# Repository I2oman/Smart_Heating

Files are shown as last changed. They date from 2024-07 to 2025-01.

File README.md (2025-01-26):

# Smart Heating Controller Attachment

This repository contains the design, firmware, and web interface for a **Smart Heating Controller Attachment** that enhances an existing heating system with Wi-Fi functionality. With this attachment, you can control your heating remotely, set timers, and enjoy advanced automation without replacing the original controller.

<p align="center">
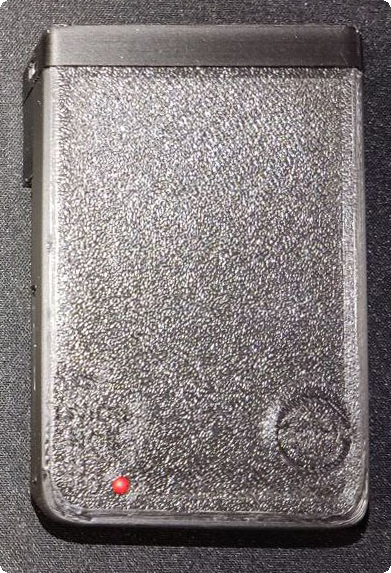
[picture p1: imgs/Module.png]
Controller Attachment
  
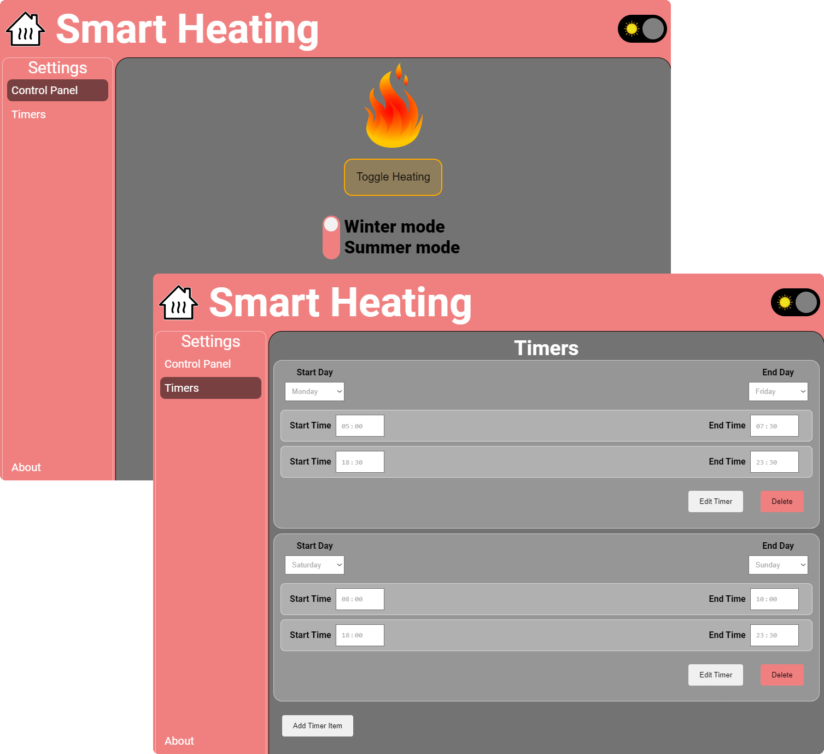
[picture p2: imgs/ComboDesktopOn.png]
Web Interface
  
</p>

---

## Features

### 1. **Wi-Fi Control**

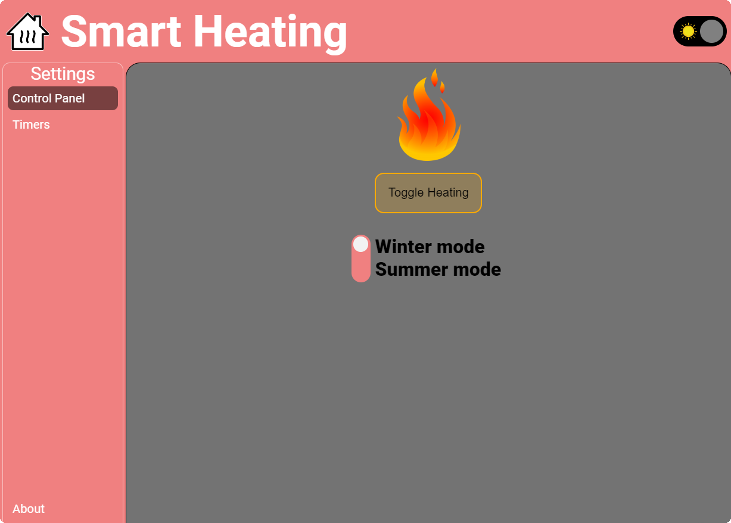
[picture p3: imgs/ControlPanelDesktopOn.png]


- Turn your heating system **ON** or **OFF** remotely via a web interface.
- Adjust settings conveniently without physical access to the controller.

#### Light and Dark Themes, On/Off State, and Mobile/Desktop View

The web interface is responsive and supports:

- **Light and Dark themes** with a toggle switch.

<p align="center">
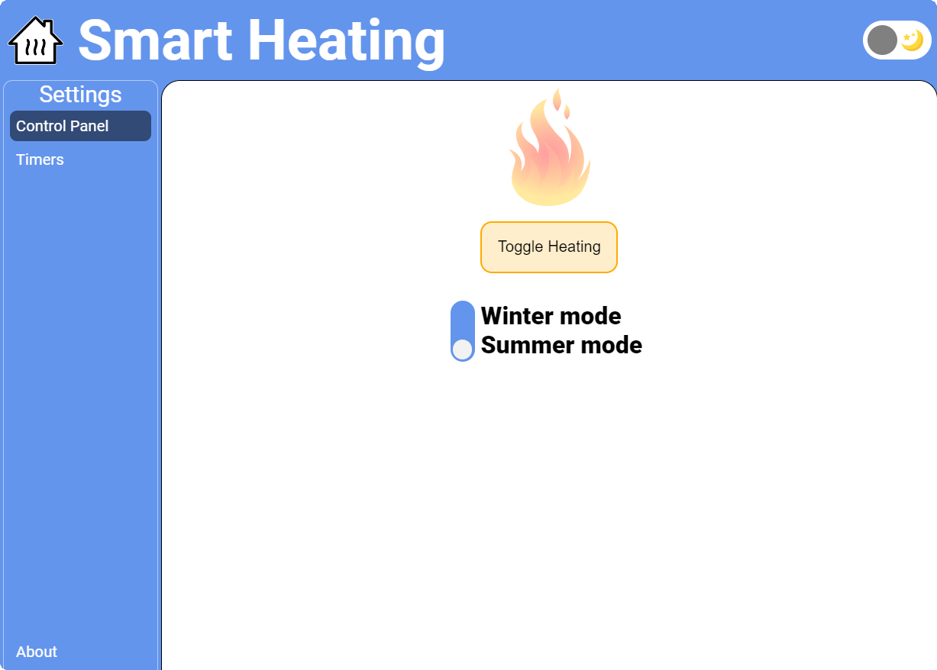
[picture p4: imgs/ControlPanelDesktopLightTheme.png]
Light Theme
  
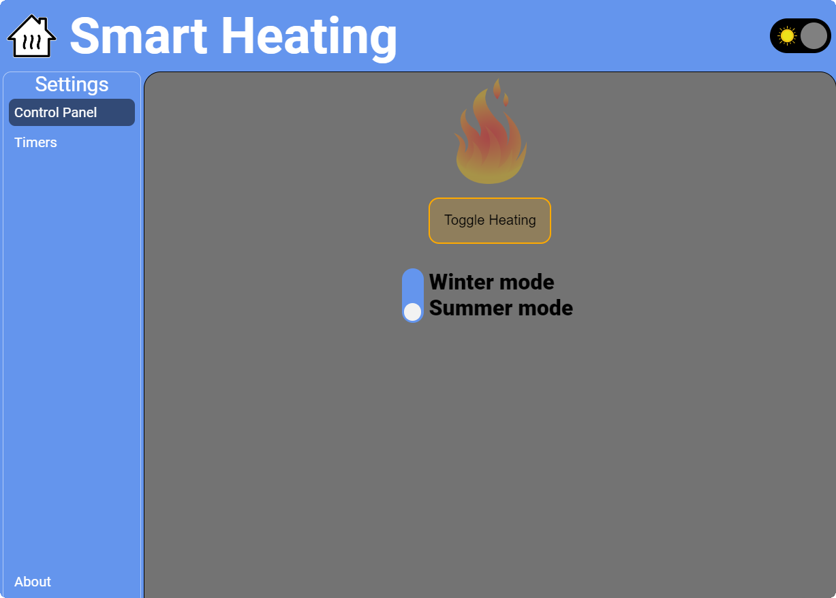
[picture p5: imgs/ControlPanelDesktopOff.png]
Dark Theme
  
</p>

- Visual indication of heating states:
  - **Red**: Heating is ON.
  - **Blue**: Heating is OFF.

<p align="center">
  Heating On
  Heating Off
</p>

- Optimized views for both **mobile** and **desktop** devices.

<p align="center">
  Desktop View
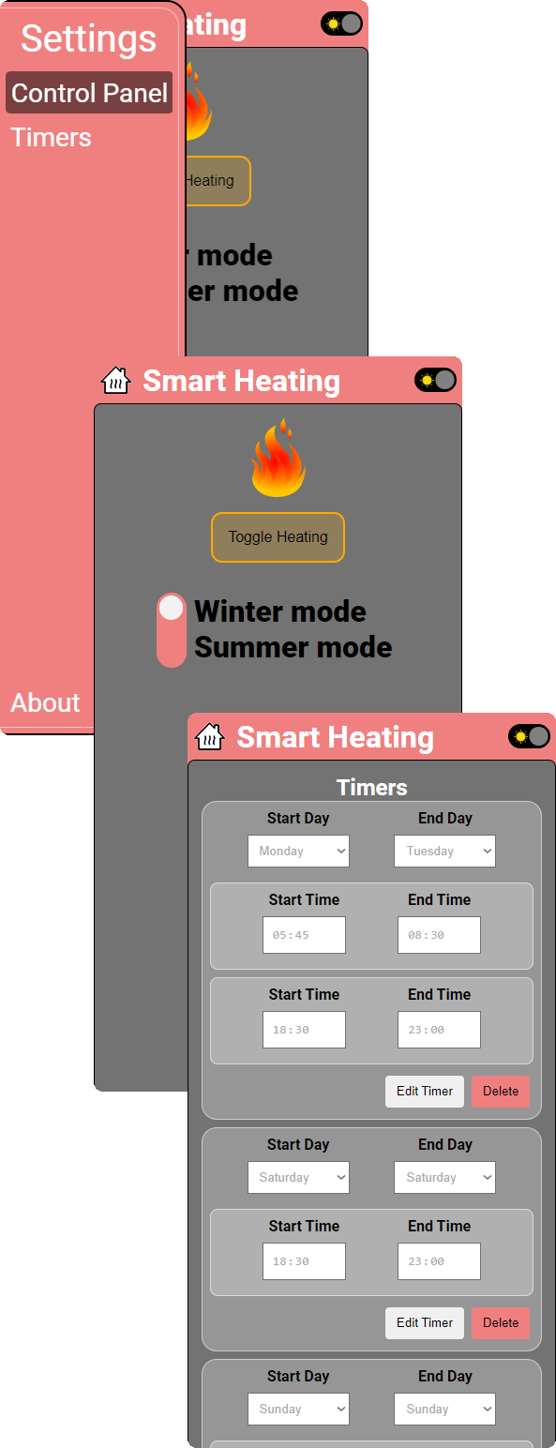
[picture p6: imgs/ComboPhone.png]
Mobile View
  
</p>

Try a preview of the website here: [Website Preview](https://htmlpreview.github.io/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)

---

### 2. **Flexible Timer Configuration**

<p align="center">
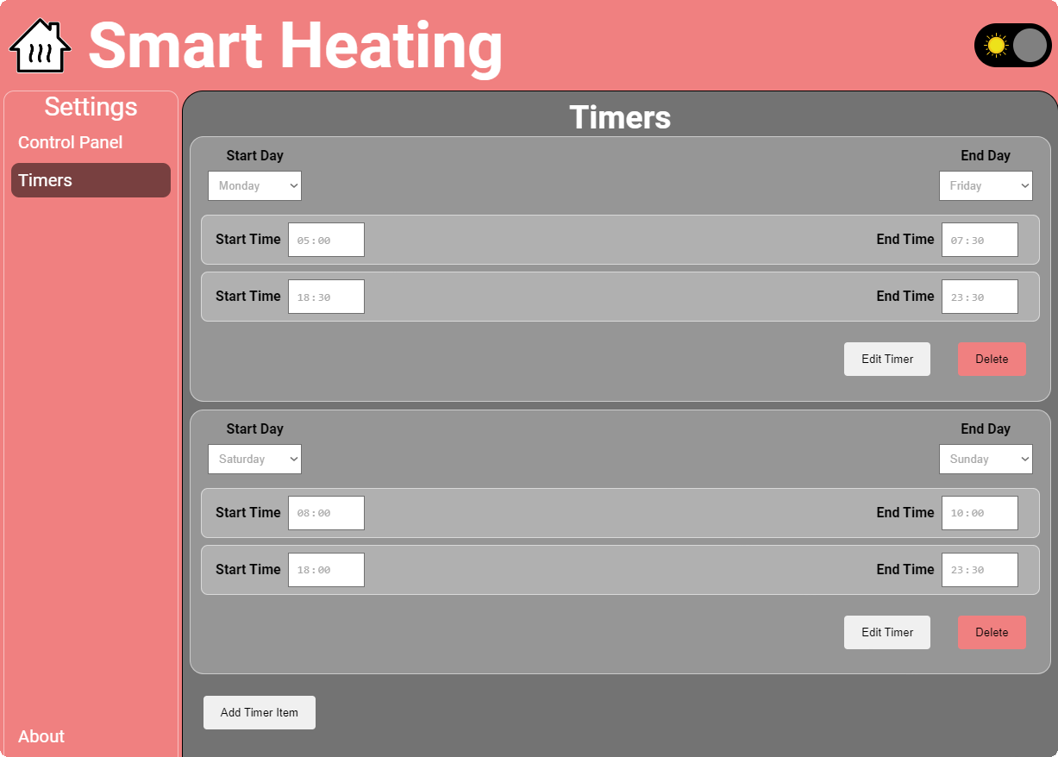
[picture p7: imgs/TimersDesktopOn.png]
Website Timer Page Dark
  
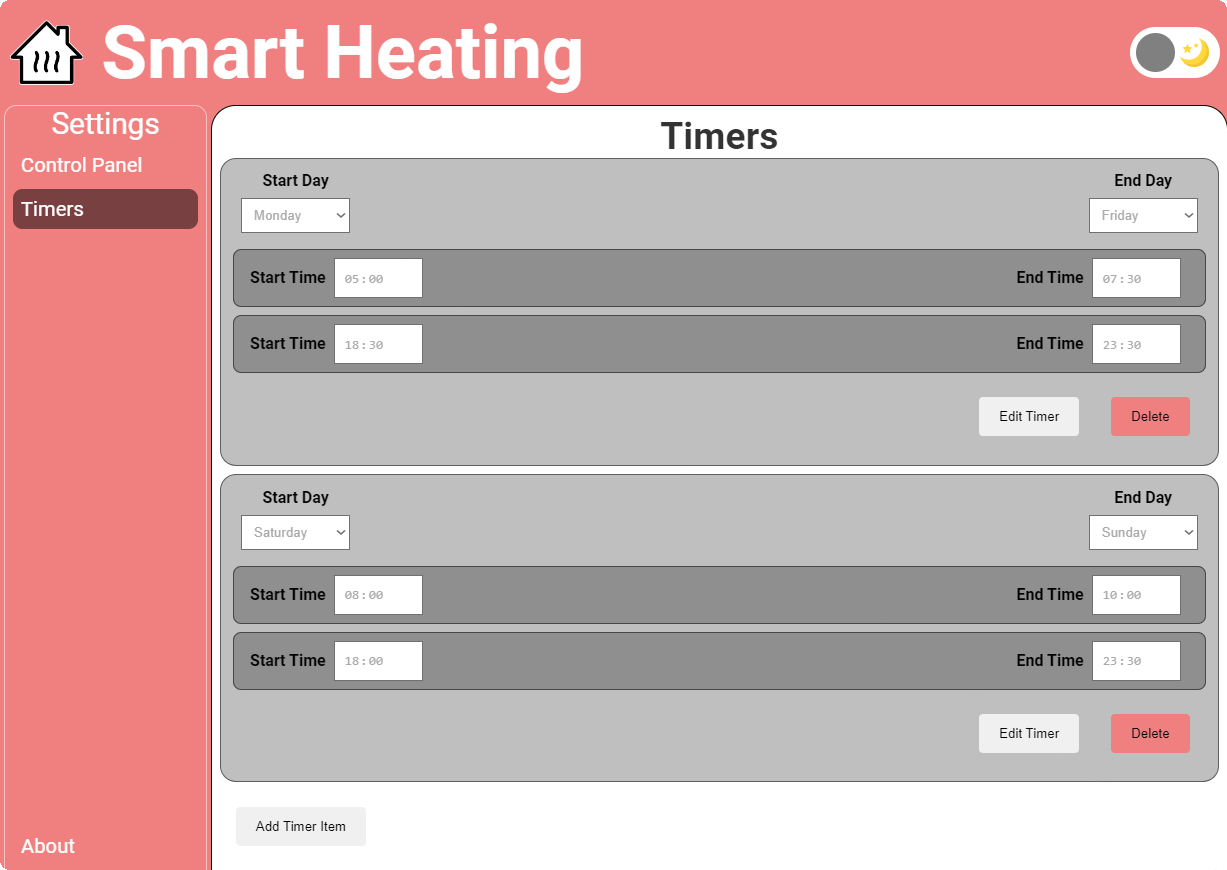
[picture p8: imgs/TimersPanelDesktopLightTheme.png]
Website Timer Page Light
  
</p>

- Set timers for specific days or ranges of days, such as:
  - **Monday only**
  - **Monday to Friday**
  - **Saturday to Sunday**
  - Or any other custom day combinations.
- Configure hour-specific timers within each day or day range:
  - Example: From **8:00 AM to 10:00 AM** and **6:00 PM to 10:00 PM**.
- Timers are stored in the controller’s memory:
  - Settings remain intact even after a restart or power outage.

---

### 3. Assembly Guide

#### 1. All the Pieces Needed to Assemble

Below is an image showing all the components and 3D-printed parts required to assemble the Smart Heating Controller (excluding the 1kΩ and 10kΩ resistors). This includes the ESP32 microcontroller, servo motor, touch sensor, LED, resistors, screws, and custom 3D-printed parts.

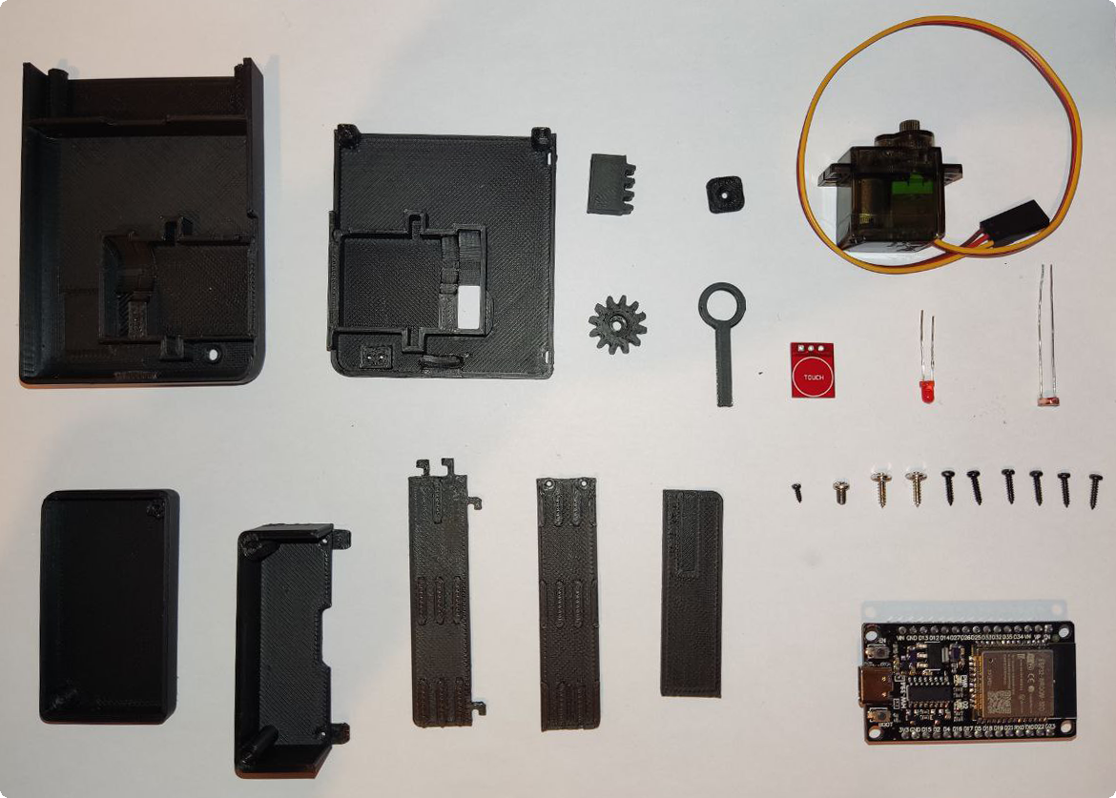
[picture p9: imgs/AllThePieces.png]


Carefully ensure you have all the parts before starting assembly. The 3D-printed case and gear mechanism were designed specifically for this project and should fit together seamlessly.

### 2. Electric Circuit and Soldering Manual

The circuit diagram illustrates how all the components are connected to the ESP32 microcontroller. This includes the servo motor, touch sensor, LED, and resistors.

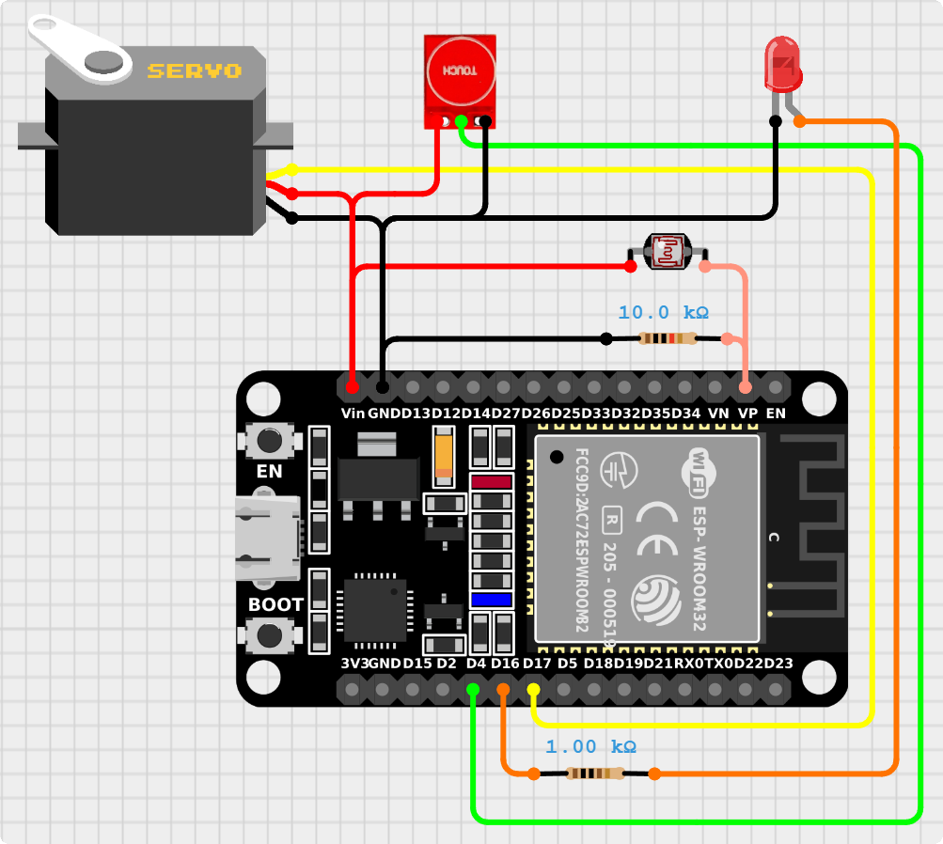
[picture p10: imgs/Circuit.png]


#### Soldering Instructions:

1. Solder a pull-up 10kΩ resistor between the photocell input pin and ground.
2. Solder the 1kΩ resistor to the LED to limit the current.
3. Connect the servo motor to the appropriate GPIO pin as shown in the circuit.
4. Connect the touch sensor to the appropriate GPIO pin as shown in the circuit.
5. Double-check all connections before powering the circuit to avoid any damage to the components.

#### Notes:

- Follow the diagram carefully to ensure correct wiring.
- Use a multimeter to test the continuity of the connections after soldering.
- For safety, keep the circuit powered off during the soldering process.

By following these steps and using the provided diagrams, you can easily assemble and set up your Smart Heating Controller system. For additional guidance or troubleshooting, refer to the project documentation or raise an issue in this repository.

### 4. **Battery Backup**

The battery pack is made by recycling single-use e-cigarettes, giving new life to discarded batteries while promoting sustainability.

To create this battery pack, I used:

- An **MT3608 boost converter** to step up the voltage for the system.
- A **TP4056 charging module** to safely charge the recycled batteries and manage power.

The circuit diagram below illustrates how the components are connected:

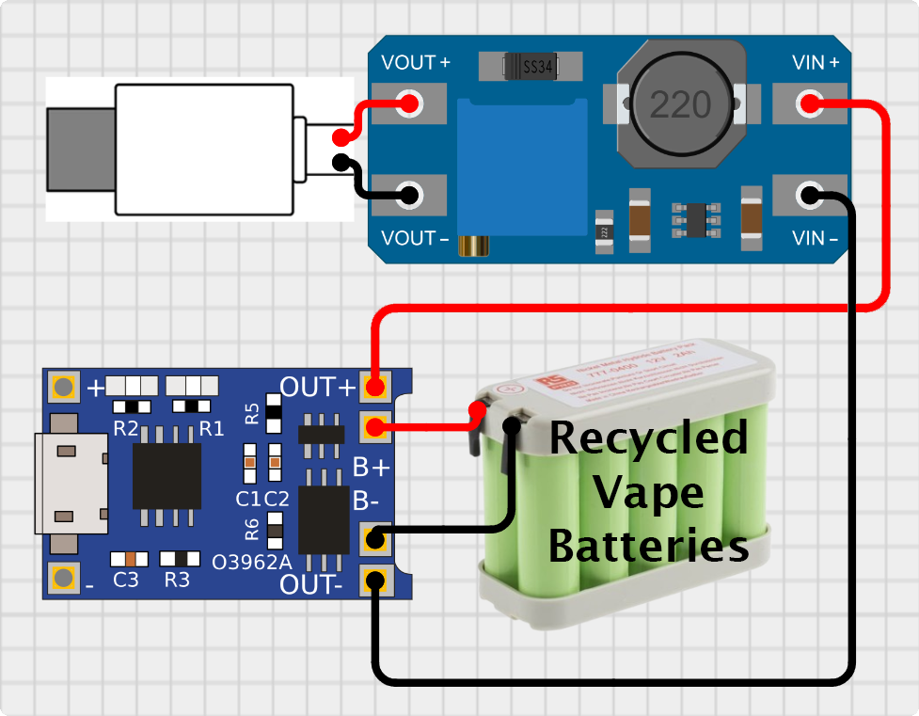
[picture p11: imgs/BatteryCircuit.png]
Battery Circuit


Additionally, here's an image of the assembled battery pack created from recycled vape batteries. This pack provides a reliable and sustainable power solution for the Smart Heating Controller:

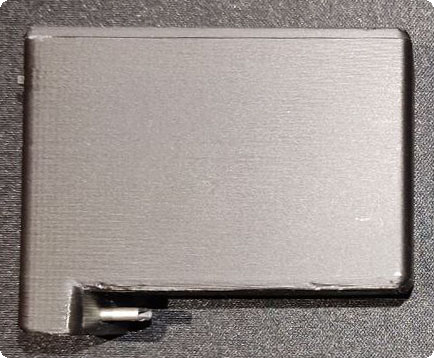
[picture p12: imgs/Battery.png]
Battery Backup


- Provides a **24–26 hour battery backup**:
  - Can be replaced daily with a fully charged one.
  - Supports on-site charging for uninterrupted operation.

---

## Components

1. **Firmware:**

   - Written in Arduino-compatible C++ for reliability and ease of customization.

2. **Hardware:**

   - Designed as an add-on to fit existing heating controllers.
   - Equipped with a robust battery system for power resilience.

3. **Web Interface:**
   - A user-friendly dashboard to manage heating, timers, and automation settings.

---

## How It Works

### Initial Setup

In the `.ino` firmware file, a maintenance mode allows uploading HTML/CSS/JS files for the web interface to the ESP32.

1. Ensure the `#define MAINTENANCE` line is uncommented in the firmware.
2. Upload the firmware through the Arduino IDE.
3. Open the serial terminal and wait for the message: `"Done uploading!!!"`.
4. After successful upload, comment out the `#define MAINTENANCE` line and re-upload the firmware for normal operation.

<p align="center">
  Arduino IDE Maintenance Mode
</p>

---

### Normal Operation

- **Installation:** Attach the module to your existing heating controller.
- **Setup:** Connect to the Wi-Fi network and access the web interface.
- **Operation:** Configure timers, toggle heating, and let the system handle the rest.

---

## Photos

### Heating Controller with Module Detached

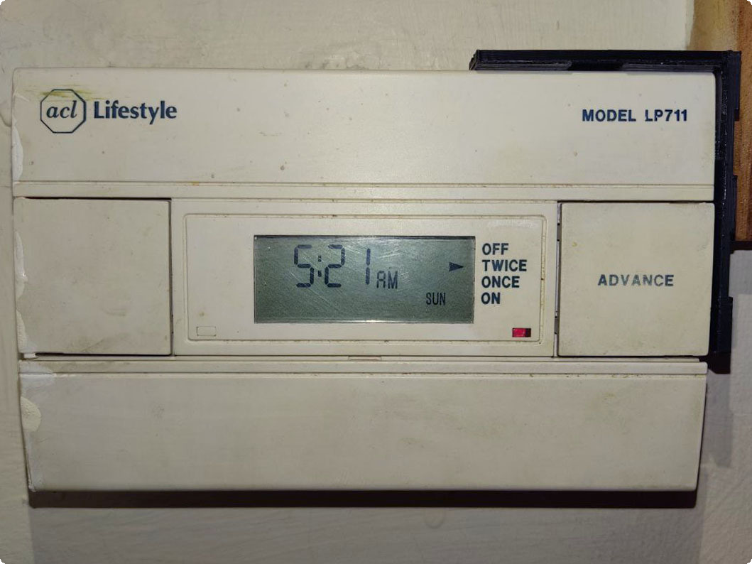
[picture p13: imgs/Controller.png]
Controller Module Detached


### Module and Battery Photo

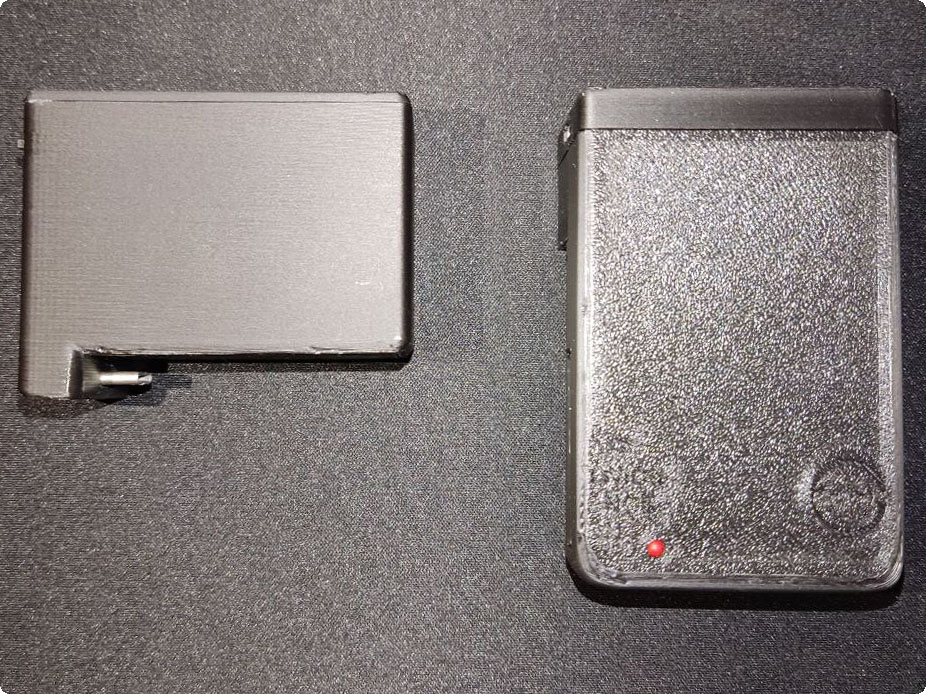
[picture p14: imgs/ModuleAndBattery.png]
Module and Battery


### Module Rear View

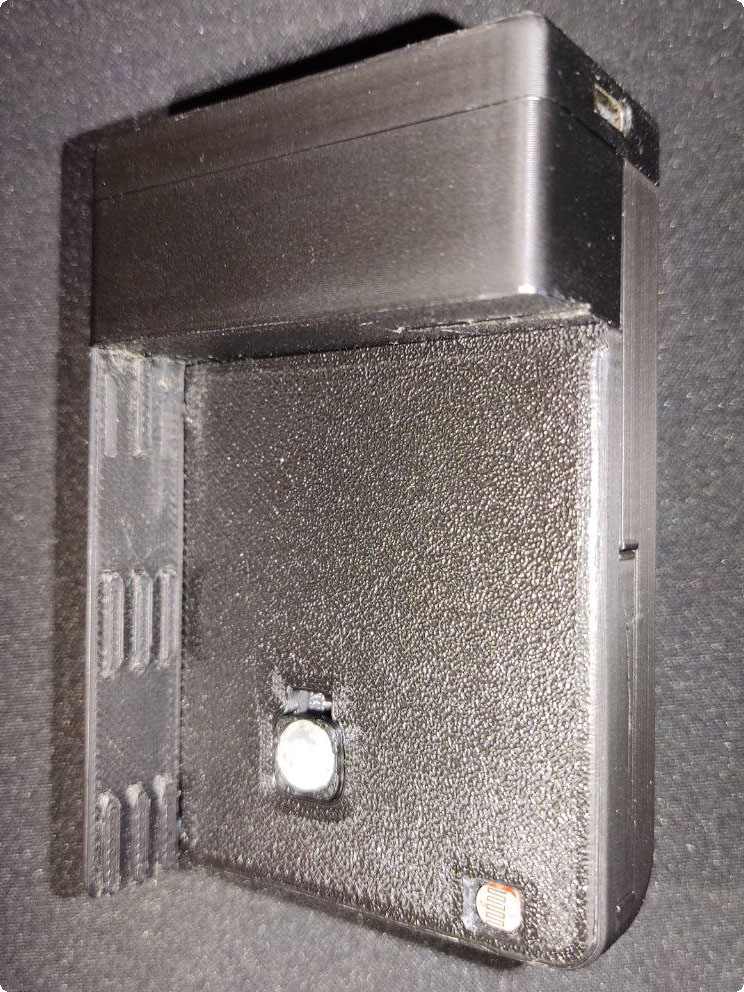
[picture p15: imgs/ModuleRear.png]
Module Rear View


### Website

<p align="center">
  Desktop dark theme on
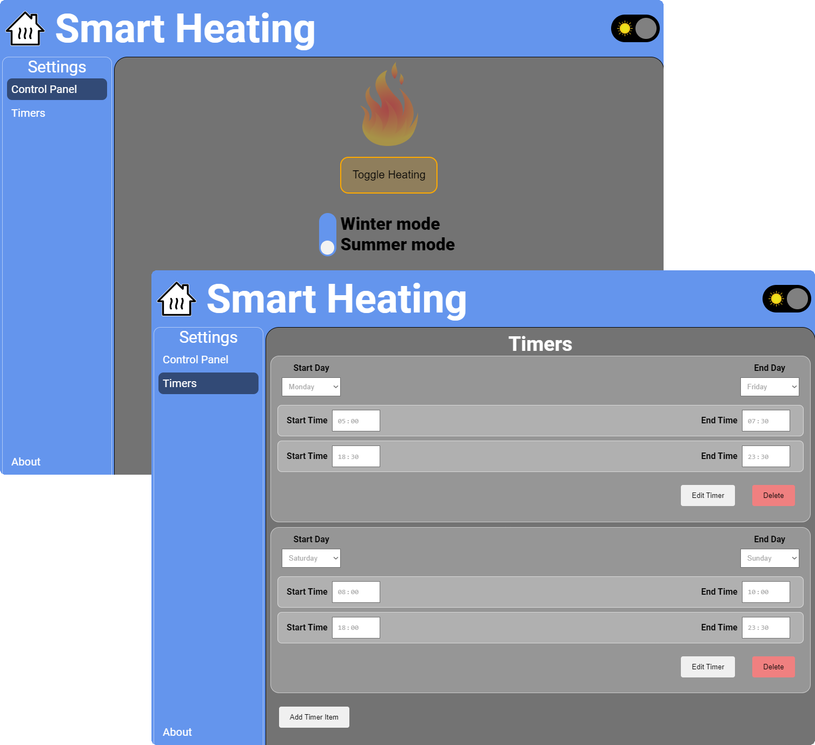
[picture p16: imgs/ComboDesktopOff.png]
Desktop dark theme off
  
</p>
<p align="center">
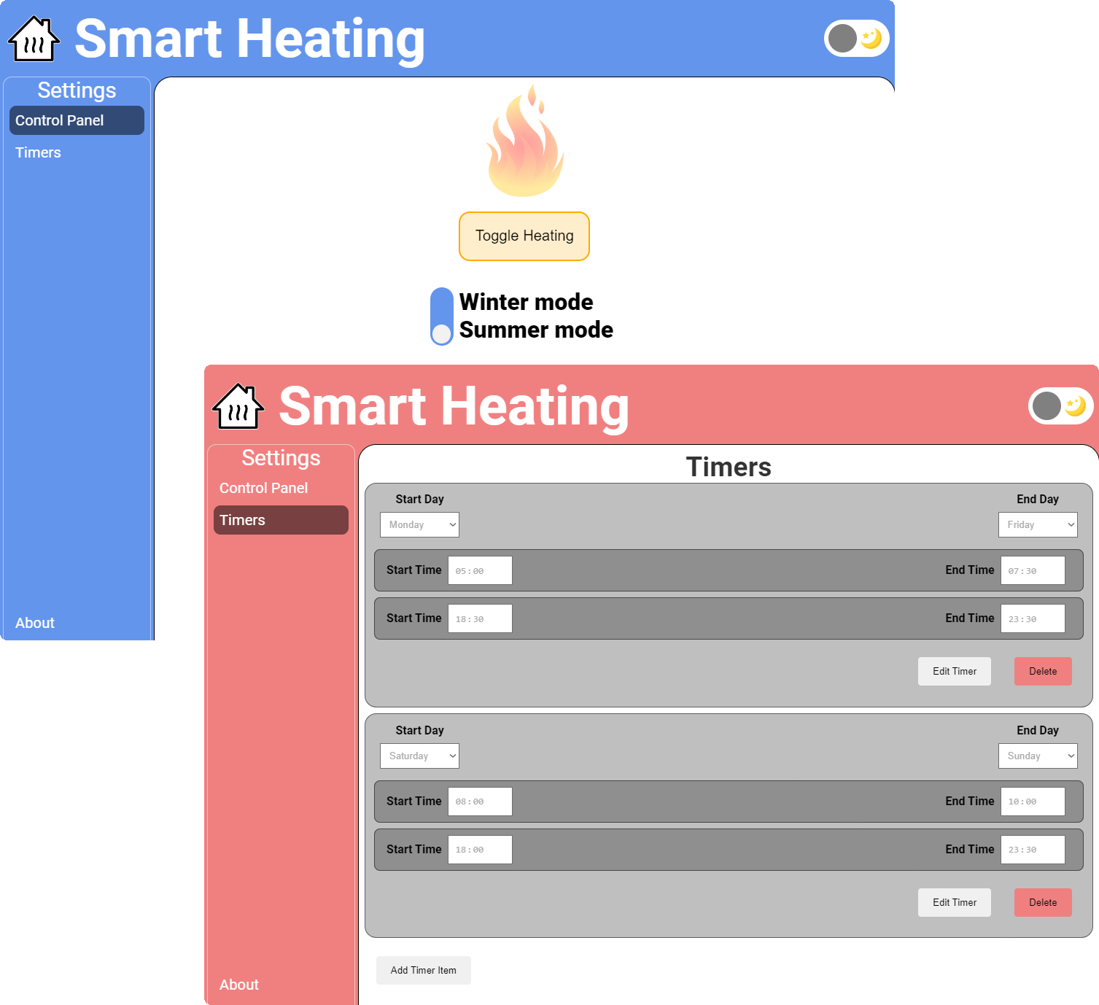
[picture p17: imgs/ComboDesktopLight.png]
Desktop light theme combined
  
  Mobile
</p>

### Heating Controller with Module Attached

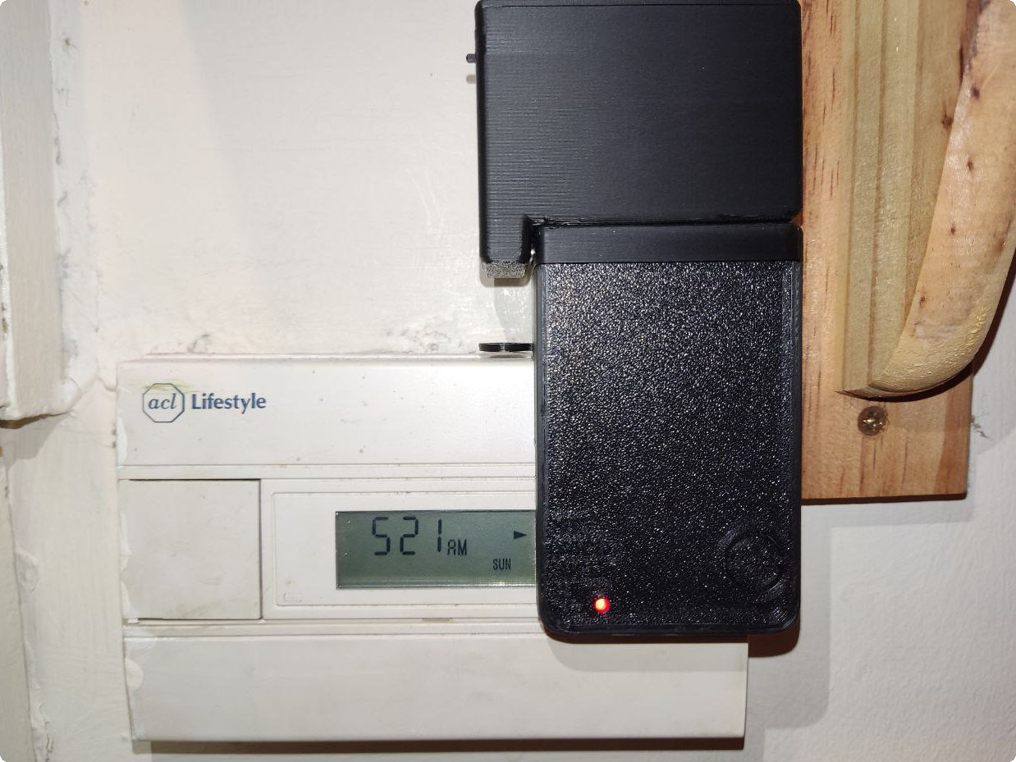
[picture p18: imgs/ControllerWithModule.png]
Controller with Module Attached


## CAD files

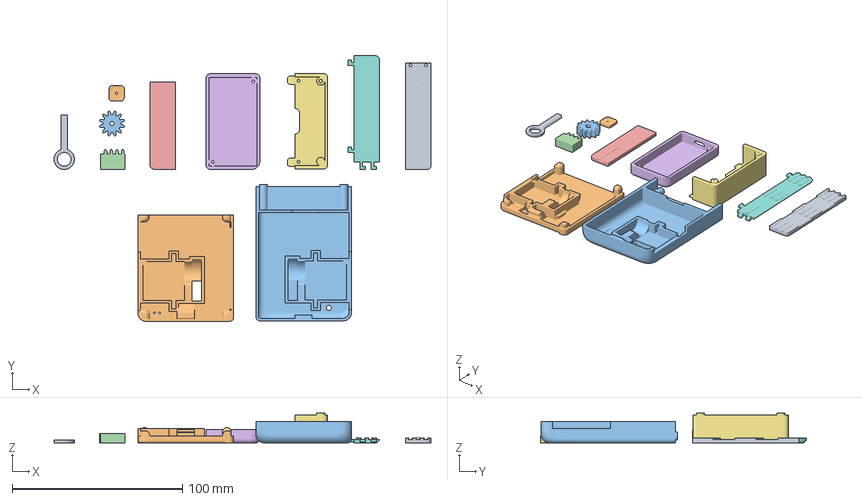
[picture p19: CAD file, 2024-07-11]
Smart_Heating_3DModels/Heating switch v26.3mf
221.4 x 156.1 x 17.5 mm
Heating switch v26.stl_1
Heating switch v26.stl_2
Heating switch v26.stl_6
Heating switch v26.stl_7
Heating switch v26.stl_3
Heating switch v26.stl_9
Heating switch v26.stl_10
Heating switch v26.stl_8
Heating switch v26.stl_5
Heating switch v26.stl_4
Heating switch v26.stl_11

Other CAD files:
Smart_Heating_3DModels/Heating switch v26.stl

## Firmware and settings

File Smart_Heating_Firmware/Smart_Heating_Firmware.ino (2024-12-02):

#include <Arduino.h>
#include <time.h>
#include <esp_sntp.h>
#ifdef ESP32
#include <WiFi.h>
#include <AsyncTCP.h>
#elif defined(ESP8266)
#include <ESP8266WiFi.h>
#include <ESPAsyncTCP.h>
#endif
#include <ESPAsyncWebServer.h>
#include <SPIFFS.h>
#include <ArduinoJson.h>

#include "WiFiCredentials.h"

// #define MAINTENANCE

#ifdef MAINTENANCE
#include "maintenance.h"
#endif

#include "Heating.h"
#include "WeeklyTimers.h"

#define LGRS 36
#define LED 16
#define BTN 4
#define SERVO 17

const char *time_zone = "GMT0BST,M3.5.0/1,M10.5.0";
const char *ntpServer1 = "pool.ntp.org";
const char *ntpServer2 = "time.nist.gov";

IPAddress local_IP(192, 168, 0, 225);
IPAddress gateway(192, 168, 0, 1);
IPAddress subnet(255, 255, 255, 0);
IPAddress primaryDNS(8, 8, 8, 8);
IPAddress secondaryDNS(8, 8, 4, 4);

AsyncWebServer server(80);
AsyncWebSocket ws("/ws");

Heating heating(BTN, LGRS, LED, SERVO);
WeeklyTimers heatingTimers;

void setup() {
  Serial.begin(115200);

  if (!SPIFFS.begin(true)) {
    Serial.println("An error has occurred while mounting SPIFFS");
    return;
  }

#ifdef MAINTENANCE
  delay(5000);
  refreshFiles();
  while (1) {}
#endif

  Serial.print("Connecting to ");
  Serial.println(ssid);

  WiFi.mode(WIFI_STA);
  if (!WiFi.config(local_IP, gateway, subnet, primaryDNS, secondaryDNS)) {
    Serial.println("STA Failed to configure");
  }
  WiFi.begin(ssid, password);
  while (WiFi.status() != WL_CONNECTED) {
    delay(1000);
    Serial.print(".");
    if (WiFi.waitForConnectResult() != WL_CONNECTED) {
      Serial.printf("WiFi Failed!\n");
      return;
    }
  }

  configTzTime(time_zone, ntpServer1, ntpServer2);

  Serial.println();
  Serial.println("WiFi connected.");
  Serial.println("IP address: ");
  Serial.println(WiFi.localIP());

  loadWeeklyTimers();

  setupServer();
}

void setupServer() {
  server.serveStatic("/", SPIFFS, "/").setDefaultFile("controlpanel.html");
  server.serveStatic("/controlpanel", SPIFFS, "/").setDefaultFile("controlpanel.html");
  server.serveStatic("/timers", SPIFFS, "/").setDefaultFile("timers.html");
  server.serveStatic("/about", SPIFFS, "/").setDefaultFile("about.html");
  server.onNotFound(notFound);

  ws.onEvent(onWebSocketEvent);
  server.addHandler(&ws);

  server.begin();
  Serial.println("HTTP server started");
}

void notFound(AsyncWebServerRequest *request) {
  request->send(SPIFFS, "/notFound.html", "text/html");
}

void onWebSocketEvent(AsyncWebSocket *server, AsyncWebSocketClient *client, AwsEventType type, void *arg, uint8_t *data, size_t len) {
  if (type == WS_EVT_CONNECT) {
    Serial.println("WebSocket client connected");

    DynamicJsonDocument systemStatus(1024);
    systemStatus["action"] = "init_update";
    systemStatus["heatingStatus"] = !heating.togglingError() ? heating.status() ? "heatingOn" : "heatingOff" : "toggle_error";
    systemStatus["heatingMode"] = heating.getMode();

    struct tm timeinfo;
    if (getLocalTime(&timeinfo)) {
      char dateBuffer[11];
      snprintf(dateBuffer, sizeof(dateBuffer), "%02d/%02d/%04d", timeinfo.tm_mday, timeinfo.tm_mon + 1, timeinfo.tm_year + 1900);
      systemStatus["date"] = dateBuffer;

      char timeBuffer[6];
      snprintf(timeBuffer, sizeof(timeBuffer), "%02d:%02d", timeinfo.tm_hour, timeinfo.tm_min);
      systemStatus["time"] = timeBuffer;
    } else {
      Serial.println("Failed to obtain time");
    }

    String status;
    serializeJson(systemStatus, status);
    client->text(status);

  } else if (type == WS_EVT_DISCONNECT) {
    Serial.println("WebSocket client disconnected");
  } else if (type == WS_EVT_DATA) {
    DynamicJsonDocument requestJson(1024);
    DeserializationError error = deserializeJson(requestJson, data, len);

    if (error) {
      Serial.print(F("deserializeJson() failed: "));
      Serial.println(error.f_str());
      return;
    }

    String output;
    serializeJson(requestJson, output);
    Serial.println(output);

    const char *action = requestJson["action"];

    if (strcmp(action, "switchHeatingMode") == 0) {
      if (requestJson["heatingMode"].as<bool>()) {
        heating.setMode(1);
        if (heating.togglingError()) return;

        struct tm timeinfo;
        if (getLocalTime(&timeinfo)) {
          uint16_t currentTimeValue = timeinfo.tm_hour * 60 + timeinfo.tm_min;

          if (heatingTimers.getDayTimerCount() == 0) {
            if (heating.status()) heating.toggleHeating();
            return;
          }

          static bool dayHaveTimer = 0;

          for (DayTimer dayTimer : heatingTimers.getDayTimersList()) {
            DayTimer::DayPair days = dayTimer.getDays();
            if ((days.startDay <= (timeinfo.tm_wday + 6) % 7) && ((timeinfo.tm_wday + 6) % 7 <= days.endDay)) {
              dayHaveTimer = 1;
              for (HeatingTimer heatingTimer : dayTimer.getTimersList()) {
                if ((heatingTimer.getValue()[0] <= currentTimeValue) && (currentTimeValue <= heatingTimer.getValue()[1])) {
                  if (heating.togglingError()) return;
                  heating.userToggleHeating();
                }
              }
            }
          }

          if (!dayHaveTimer) {
            if (heating.togglingError()) return;
            if (heating.status()) heating.toggleHeating();
          }
        } else {
          if (heating.togglingError()) return;
          if (heating.status()) heating.toggleHeating();
        }

      } else {
        if (!heating.togglingError() && heating.status()) heating.userToggleHeating();
        heating.setMode(0);
      }
      Serial.println(heating.getMode());

      saveWeeklyTimers();
    } else if (strcmp(action, "togleHeating") == 0) {
      if (heating.getMode()) {
        heating.userToggleHeating();
      }
    } else if (strcmp(action, "addDayTimer") == 0) {
      DayTimer dayTimer;
      JsonObject jsonDayTimer = requestJson["dayTimer"].as<JsonObject>();

      DayTimer::DayPair dayPair;
      uint8_t startDay = jsonDayTimer["startDay"];
      uint8_t endDay = jsonDayTimer["endDay"];
      dayPair = { startDay, endDay };

      dayTimer.modifyDays(dayPair);

      JsonArray timersArray = jsonDayTimer["timers"].as<JsonArray>();
      for (JsonObject jsonTimer : timersArray) {
        HeatingTimer heatingTimer;

        HeatingTimer::Time startTime;
        uint8_t startTimeHours = jsonTimer["startTime"]["hours"];
        uint8_t startTimeMinutes = jsonTimer["startTime"]["minutes"];
        startTime = { startTimeHours, startTimeMinutes };

        HeatingTimer::Time endTime;
        uint8_t endTimeHours = jsonTimer["endTime"]["hours"];
        uint8_t endTimeMinutes = jsonTimer["endTime"]["minutes"];
        endTime = { endTimeHours, endTimeMinutes };

        HeatingTimer::TimePair timePair = { startTime, endTime };

        heatingTimer.modify(timePair);

        dayTimer.addTimer(heatingTimer);
      }

      heatingTimers.addDayTimer(dayTimer);

      ws.textAll(getDayTimersSJson());

      saveWeeklyTimers();
    } else if (strcmp(action, "modifyDayTimer") == 0) {
      unsigned long dayTimerId = requestJson["dayTimerId"].as<unsigned long>();
      JsonArray changes = requestJson["changes"].as<JsonArray>();
      for (JsonObject change : changes) {
        const char *changeAction = change["action"];
        if (strcmp(changeAction, "modifyDays") == 0) {
          JsonObject jsonDayTimer = change["dayTimer"].as<JsonObject>();

          DayTimer::DayPair dayPair;
          uint8_t startDay = jsonDayTimer["startDay"];
          uint8_t endDay = jsonDayTimer["endDay"];
          dayPair = { startDay, endDay };

          heatingTimers.getDayTimer(dayTimerId).modifyDays(dayPair);
        } else if (strcmp(changeAction, "addTimers") == 0) {
          JsonArray timersArray = change["timers"].as<JsonArray>();

          for (JsonObject jsonTimer : timersArray) {
            uint8_t startTimeHours = jsonTimer["startTime"]["hours"];
            uint8_t startTimeMinutes = jsonTimer["startTime"]["minutes"];
            HeatingTimer::Time startTime = { startTimeHours, startTimeMinutes };

            uint8_t endTimeHours = jsonTimer["endTime"]["hours"];
            uint8_t endTimeMinutes = jsonTimer["endTime"]["minutes"];
            HeatingTimer::Time endTime = { endTimeHours, endTimeMinutes };

            HeatingTimer heatingTimer({ startTime, endTime });

            heatingTimers.getDayTimer(dayTimerId).addTimer(heatingTimer);
          }
        } else if (strcmp(changeAction, "modifyTimers") == 0) {
          JsonArray timersArray = change["timers"].as<JsonArray>();
          for (JsonObject jsonTimer : timersArray) {
            unsigned long timerId = jsonTimer["timerId"].as<unsigned long>();

            JsonObject timerJson = jsonTimer["timer"].as<JsonObject>();

            uint8_t startTimeHours = timerJson["startTime"]["hours"];
            uint8_t startTimeMinutes = timerJson["startTime"]["minutes"];
            HeatingTimer::Time startTime = { startTimeHours, startTimeMinutes };

            uint8_t endTimeHours = timerJson["endTime"]["hours"];
            uint8_t endTimeMinutes = timerJson["endTime"]["minutes"];
            HeatingTimer::Time endTime = { endTimeHours, endTimeMinutes };

            heatingTimers.getDayTimer(dayTimerId).getTimer(timerId).modify({ startTime, endTime });
          }
        } else if (strcmp(changeAction, "deleteTimers") == 0) {
          JsonArray jsonTimerIds = change["timerIds"].as<JsonArray>();
          for (unsigned long id : jsonTimerIds) {
            heatingTimers.getDayTimer(dayTimerId).deleteTimer(id);
          }
        }
      }

      ws.textAll(getDayTimersSJson());

      saveWeeklyTimers();
    } else if (strcmp(action, "deleteDayTimer") == 0) {
      heatingTimers.deleteDayTimer(requestJson["dayTimerId"].as<unsigned long>());

      ws.textAll(getDayTimersSJson());

      saveWeeklyTimers();
    } else if (strcmp(action, "getDayTimers") == 0) {
      client->text(getDayTimersSJson());
    }

    displayHeatingTimers();

    DynamicJsonDocument responseJson(1024);
    responseJson["status"] = "success";
    responseJson["message"] = "Command received";
    String response;
    serializeJson(responseJson, response);
    client->text(response);
  }
}

String getDayTimersSJson() {
  DynamicJsonDocument dayTimersJson(4096);
  dayTimersJson["action"] = "dayTimersList_update";

  JsonArray dayTimersArray = dayTimersJson.createNestedArray("dayTimers");

  for (const DayTimer &dayTimer : heatingTimers.getDayTimersList()) {
    JsonObject dayTimerObj = dayTimersArray.createNestedObject();

    dayTimerObj["id"] = dayTimer.getId();
    auto days = dayTimer.getDays();
    dayTimerObj["startDay"] = days.startDay;
    dayTimerObj["endDay"] = days.endDay;

    JsonArray timersArray = dayTimerObj.createNestedArray("timers");

    for (const HeatingTimer &heatingTimer : dayTimer.getTimersList()) {
      JsonObject heatingTimerObj = timersArray.createNestedObject();
      heatingTimerObj["id"] = heatingTimer.getId();
      auto timer = heatingTimer.getTimer();
      heatingTimerObj["startTime"]["hours"] = timer.startTime.hours;
      heatingTimerObj["startTime"]["minutes"] = timer.startTime.minutes;
      heatingTimerObj["endTime"]["hours"] = timer.endTime.hours;
      heatingTimerObj["endTime"]["minutes"] = timer.endTime.minutes;
    }
  }

  String response;
  serializeJson(dayTimersJson, response);
  return response;
}

void displayHeatingTimers() {
  Serial.println("Displaying all heating timers:");

  for (const DayTimer &dayTimer : heatingTimers.getDayTimersList()) {
    DayTimer::DayPair days = dayTimer.getDays();
    Serial.printf("DayTimer %lu: %u to %u\n", dayTimer.getId(), days.startDay, days.endDay);

    for (const HeatingTimer heatingTimer : dayTimer.getTimersList()) {
      HeatingTimer::TimePair timePair = heatingTimer.getTimer();
      Serial.printf("  Timer %lu: %u:%u to %u:%u\n", heatingTimer.getId(), timePair.startTime.hours, timePair.startTime.minutes, timePair.endTime.hours, timePair.endTime.minutes);
    }
  }
}

void saveWeeklyTimers() {
  DynamicJsonDocument doc(4096);
  doc["winterMode"] = heating.getMode();

  JsonArray timersArray = doc.createNestedArray("dayTimers");

  for (const DayTimer &dayTimer : heatingTimers.getDayTimersList()) {
    JsonObject dayTimerObj = timersArray.createNestedObject();
    dayTimerObj["id"] = dayTimer.getId();

    JsonObject days = dayTimerObj.createNestedObject("days");
    days["startDay"] = dayTimer.getDays().startDay;
    days["endDay"] = dayTimer.getDays().endDay;

    JsonArray heatingTimersArray = dayTimerObj.createNestedArray("timers");
    for (const HeatingTimer &heatingTimer : dayTimer.getTimersList()) {
      JsonObject heatingTimerObj = heatingTimersArray.createNestedObject();
      heatingTimerObj["id"] = heatingTimer.getId();
      heatingTimerObj["startTime"]["hours"] = heatingTimer.getTimer().startTime.hours;
      heatingTimerObj["startTime"]["minutes"] = heatingTimer.getTimer().startTime.minutes;
      heatingTimerObj["endTime"]["hours"] = heatingTimer.getTimer().endTime.hours;
      heatingTimerObj["endTime"]["minutes"] = heatingTimer.getTimer().endTime.minutes;
    }
  }

  File file = SPIFFS.open("/timers.json", FILE_WRITE);
  if (!file) {
    Serial.println("Failed to open file for writing");
    return;
  }

  if (serializeJson(doc, file) == 0) {
    Serial.println("Failed to write to file");
  }

  file.close();
  Serial.println("Timers saved to SPIFFS");
}

void loadWeeklyTimers() {
  File file = SPIFFS.open("/timers.json");
  if (!file) {
    Serial.println("Failed to open file for reading");
    return;
  }

  DynamicJsonDocument doc(4096);

  DeserializationError error = deserializeJson(doc, file);
  if (error) {
    Serial.println("Failed to read file, using default configuration");
    heating.begin(0, 0);
    return;
  }
  file.close();

  bool uSelect = 0;

  struct tm timeinfo;
  if (getLocalTime(&timeinfo)) {
    uint16_t currentTimeValue = timeinfo.tm_hour * 60 + timeinfo.tm_min;
    JsonArray timersArray = doc["dayTimers"].as<JsonArray>();
    for (JsonObject jsonDayTimer : timersArray) {
      uint8_t startDay = jsonDayTimer["days"]["startDay"];
      uint8_t endDay = jsonDayTimer["days"]["endDay"];
      DayTimer::DayPair dayPair = { startDay, endDay };

      DayTimer dayTimer(dayPair);

      JsonArray timersArray = jsonDayTimer["timers"].as<JsonArray>();
      for (JsonObject jsonTimer : timersArray) {
        uint8_t startTimeHours = jsonTimer["startTime"]["hours"];
        uint8_t startTimeMinutes = jsonTimer["startTime"]["minutes"];
        HeatingTimer::Time startTime = { startTimeHours, startTimeMinutes };

        uint8_t endTimeHours = jsonTimer["endTime"]["hours"];
        uint8_t endTimeMinutes = jsonTimer["endTime"]["minutes"];
        HeatingTimer::Time endTime = { endTimeHours, endTimeMinutes };

        HeatingTimer::TimePair timePair = { startTime, endTime };

        HeatingTimer heatingTimer(timePair);

        dayTimer.addTimer(heatingTimer);

        if ((dayPair.startDay <= (timeinfo.tm_wday + 6) % 7) && ((timeinfo.tm_wday + 6) % 7 <= dayPair.endDay)) {
          if ((heatingTimer.getValue()[0] <= currentTimeValue) && (currentTimeValue <= heatingTimer.getValue()[1])) {
            uSelect = 1;
          }
        }
      }

      heatingTimers.addDayTimer(dayTimer);
    }
  }

  bool wMode = doc["winterMode"];

  Serial.print(wMode);
  Serial.print(" ");
  Serial.println(uSelect);

  heating.begin(wMode, uSelect);
}

void loop() {
  ws.cleanupClients();
  systemStateWebUpdate();
  systemMonitoring();
}

void systemMonitoring() {
  static unsigned long timerMillis = millis();
  static unsigned int msDelay = 0;
  if (millis() - timerMillis >= msDelay) {
    timerMillis = millis();
    struct tm timeinfo;
    if (getLocalTime(&timeinfo)) {
      if (msDelay != 5000 || timeinfo.tm_sec % 5 != 0) {
        msDelay = 5 - timeinfo.tm_sec % 5;
        msDelay *= 1000;
        if (msDelay < 500) {
          msDelay = 5000;
        }
      }
      Serial.printf("%02d/%02d/%02d, %02d:%02d:%02d, day - %d, sys - %d, uSelect - %d\n", timeinfo.tm_mday, timeinfo.tm_mon + 1, timeinfo.tm_year + 1900, timeinfo.tm_hour, timeinfo.tm_min, timeinfo.tm_sec, (timeinfo.tm_wday + 6) % 7, heating.status(), heating.getUserSelect());

      DynamicJsonDocument jsonData(1024);
      jsonData["action"] = "time_update";
      char dateBuffer[11];
      snprintf(dateBuffer, sizeof(dateBuffer), "%02d/%02d/%04d", timeinfo.tm_mday, timeinfo.tm_mon + 1, timeinfo.tm_year + 1900);
      jsonData["date"] = dateBuffer;

      char timeBuffer[6];
      snprintf(timeBuffer, sizeof(timeBuffer), "%02d:%02d", timeinfo.tm_hour, timeinfo.tm_min);
      jsonData["time"] = timeBuffer;
      String message;
      serializeJson(jsonData, message);
      ws.textAll(message);

      if (heating.getMode()) {
        if (heating.togglingError()) return;

        if (heatingTimers.getDayTimerCount() == 0) {
          if (heating.status()) heating.toggleHeating();
          return;
        }

        static bool dayHaveTimer = 0;

        for (DayTimer dayTimer : heatingTimers.getDayTimersList()) {
          DayTimer::DayPair days = dayTimer.getDays();
          if ((days.startDay <= (timeinfo.tm_wday + 6) % 7) && ((timeinfo.tm_wday + 6) % 7 <= days.endDay)) {
            dayHaveTimer = 1;
            for (HeatingTimer heatingTimer : dayTimer.getTimersList()) {
              HeatingTimer::TimePair timePair = heatingTimer.getTimer();

              uint16_t currentTimeValue = timeinfo.tm_hour * 60 + timeinfo.tm_min;
              Serial.print(heatingTimer.getValue()[0]);
              Serial.print(" (");
              Serial.print(currentTimeValue);
              Serial.print(") ");
              Serial.print(heatingTimer.getValue()[1]);
              Serial.print(", ");
              Serial.print(heating.status());
              Serial.print(" ");
              Serial.println(heating.getUserSelect());
              if ((heatingTimer.getValue()[0] == currentTimeValue) || (currentTimeValue == heatingTimer.getValue()[1])) {
                if (currentTimeValue == heatingTimer.getValue()[0] && timeinfo.tm_sec <= 10) {
                  if (!heating.status()) heating.userToggleHeating();
                } else if (currentTimeValue == heatingTimer.getValue()[1] && timeinfo.tm_sec <= 10) {
                  if (heating.status()) heating.userToggleHeating();
                }
              }
              if (heating.status() != heating.getUserSelect()) {
                heating.toggleHeating();
              }
            }
          }
        }

        if (!dayHaveTimer) {
          if (heating.togglingError()) return;
          if (heating.status()) heating.toggleHeating();
        }
      } else {
        if (heating.togglingError()) return;
        if (heating.status()) heating.toggleHeating();
      }
    } else {
      Serial.println("Failed to obtain time");
      if (heating.togglingError()) return;
      if (heating.status()) heating.toggleHeating();
    }
  }
}

void systemStateWebUpdate() {
  heating.heatingMonitor();
  if (heating.statusChanded()) {
    DynamicJsonDocument sensorData(1024);
    sensorData["action"] = "status_update";
    if (heating.getMode()) {
      sensorData["heatingStatus"] = !heating.togglingError() ? heating.status() ? "heatingOn" : "heatingOff" : "heatingError";
    } else {
      sensorData["heatingStatus"] = "heatingOff";
    }
    String message;
    serializeJson(sensorData, message);
    ws.textAll(message);
  }
}

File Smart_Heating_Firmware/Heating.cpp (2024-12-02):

#include "Heating.h"

Heating::Heating(uint8_t btnPin, uint8_t photoresistorPin, uint8_t ledPin, uint8_t servoPin, uint16_t monitoringFrequency) {
  this->btnPin = btnPin;
  this->photoresistorPin = photoresistorPin;
  this->ledPin = ledPin;
  this->servoPin = servoPin;
  this->monitoringFrequency = monitoringFrequency;

  this->heatingError = 0;
  this->heatingStatus = 0;
  this->heatingStatusPr = 0;

  this->needToToggle = 0;
}

void Heating::begin(bool winterMode, bool userSelect) {
  this->userSelect = userSelect;
  this->winterMode = winterMode;

  pinMode(btnPin, INPUT);

  pinMode(ledPin, OUTPUT);
  heatingStatus = analogRead(photoresistorPin) > 1000;
  heatingStatusPr = heatingStatus;
  digitalWrite(ledPin, heatingStatus);

  myservo.attach(servoPin);
  myservo.write(0);
}

void Heating::heatingMonitor() {
  buttonMonitor();
  if (needToToggle) {
    togglingHeating();
  }

  static unsigned long systemMonitorTimer;
  if (millis() - systemMonitorTimer >= monitoringFrequency) {
    systemMonitorTimer = millis();

    heatingStatus = analogRead(photoresistorPin) > 1000;

    if (winterMode) {
      digitalWrite(ledPin, heatingStatus);
    }

    statusChange = heatingStatus != heatingStatusPr;
    heatingStatusPr = heatingStatus;

    if (statusChange) {
      heatingError = 0;
    }
  }
}

bool Heating::statusChanded() {
  if (statusChange) {
    statusChange = 0;
    return true;
  }
  return statusChange;
}

bool Heating::togglingError() {
  return heatingError;
}

bool Heating::status() {
  return heatingStatus;
}

void Heating::buttonMonitor() {
  if (winterMode) {
    static bool btnPr = 0;
    static unsigned long btnTimer;
    if (digitalRead(btnPin) != btnPr && millis() - btnTimer >= 250) {
      btnPr = digitalRead(btnPin);
      btnTimer = millis();

      if (btnPr) {
        userToggleHeating();
      }
    }
  }
}

void Heating::setMode(bool mode) {
  winterMode = mode;
  if (!winterMode) userSelect = 0;
}

bool Heating::getMode() {
  return winterMode;
}

void Heating::userToggleHeating() {
  userSelect = !(analogRead(photoresistorPin) > 1000);
  toggleHeating();
}

bool Heating::getUserSelect() {
  return userSelect;
}

void Heating::toggleHeating() {
  needToToggle = 1;
  togglingHeating();
}

void Heating::togglingHeating() {
  static bool clicked = 0;
  static unsigned long toggleTimer;
  static bool btnBf;
  if (millis() - toggleTimer > 1000 && !clicked) {
    toggleTimer = millis();

    heatingStatus = analogRead(photoresistorPin) > 1000;
    btnBf = heatingStatus;

    myservo.write(35);
    clicked = 1;
  }
  if (millis() - toggleTimer >= 500 && millis() - toggleTimer < 1000 && needToToggle) {
    myservo.write(0);

    heatingStatus = analogRead(photoresistorPin) > 1000;
    digitalWrite(ledPin, heatingStatus);
    heatingError = heatingStatus == btnBf;

    if (heatingStatus != heatingStatusPr || heatingError || heatingStatus != btnBf) {
      statusChange = 1;
      heatingStatusPr = heatingStatus;
    }

    clicked = 0;
    needToToggle = 0;
  }
}

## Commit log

2024-08-14 Added working timers
2024-10-04 Timers logic fix
2024-10-04 Control while timer off fix
    [Smart_Heating_Firmware.ino]
2024-12-02 Optimize website for mobile, improve Arduino firmware logic, and add README
    - Optimized website layout and performance for mobile devices.
    - Enhanced logic in Arduino firmware for better functionality.
    - Added a README file with project description, photos, and setup instructions.
